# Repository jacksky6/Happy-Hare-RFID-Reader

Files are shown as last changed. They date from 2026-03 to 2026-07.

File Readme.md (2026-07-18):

# Happy Hare RFID/NFC Reader

NFC spool identification for Happy Hare. Use one NFC reader on each EMU lane, one shared reader inside the MMU body, or both. PN532 remains the default reader; PN7160, RC522, and PN5180 are available with `reader_type: pn7160`, `rc522`, and `pn5180`.

This is a system-level Klipper integration, not a plug-and-play appliance. It touches Klipper extras, Happy Hare macros, lane MCU firmware, I2C wiring, Spoolman, and optional LED effects. If you are not comfortable recovering from a Klipper config error, reflashing lane MCUs, and reading logs, expect a learning curve.

## Why This Project Is Different

Most DIY spool RFID/NFC systems put a small controller such as an ESP32 near the
reader and report tags over WiFi, MQTT, or another side channel. Others wire the
reader back to the host Raspberry Pi, which often means long SDA/SCL or USB runs
through the printer.

This project keeps the reader inside the MMU wiring domain. Each NFC reader is
connected directly to an existing Klipper MCU I2C bus, usually the MMU board or
the per-lane board inside the MMU. Klipper talks to that MCU, and the plugin
integrates the result with Happy Hare and Spoolman.

Practical hardware choices:

- **EMU / one board per lane:** per-lane readers are a natural fit. Each lane has
  its own MCU/I2C bus, so PN532 and PN7160 are both valid choices.
- **Other B-style multi-material systems with one MMU board:** PN7160 is usually
  the better choice for multiple readers on one bus because it has four
  selectable I2C addresses (`40-43` / `0x28-0x2B`). That matches many four-color
  MMU layouts.
- **Single shared reader:** PN532, PN7160, RC522, or PN5180 can be mounted
  inside the MMU body and used as a tap-before-loading reader. PN5180 is the
  SPI option when SLIX2 (ISO15693/Type-5) support is required.

For EMU installations, [`NFC Mounting Bracket/`](NFC%20Mounting%20Bracket/)
contains the printable STL and editable STEP source for the NFC-reader LED holder.

## Virtual Endstop — How Scan-Jog Finds the Tag

Per-lane installs register each lane's NFC reader as a real Klipper/Happy Hare
homing endstop (`mmu_nfc_endstop.py`, `[mmu_nfc_endstop laneN]`) — no extra
hardware or wiring, it borrows the reader the matching `[nfc_gate laneN]`
section already owns. When scan-jog searches for the tag, the forward search
is a genuine Klipper homing move (`ENDSTOP=nfc_lane<N>`) that stops the
instant the tag is detected, instead of jogging a fixed chunk and polling
afterward and hoping the tag was somewhere in that chunk. This is generated
automatically for every enabled lane by `install.sh` — there is nothing extra
to configure. See [How It Works](docs/shared/how-it-works.md) for the full
scan loop and [Configuration Reference](docs/shared/configuration.md) for the
`[mmu_nfc_endstop laneN]` keys.

The same configuration supports Happy Hare V3 and V4. The plugin registers
the software endstop on V3's shared gear rail or on the V4 drive selected by
the reader's `mmu_gate`. Lane and endstop section names are only labels; the
`nfc_gate` reference and `mmu_gate` value provide the actual binding, including
multi-unit installations.

## Operating Modes

| Mode | Hardware | Best For | Flow |
|---|---|---|---|
| Per-lane readers | One NFC reader per EMU gate/lane MCU (default PN532; PN7160, RC522, or PN5180 supported) | Automatic spool identification during lane preload | Load spool -> HH parks filament -> NFC scan-jog rotates spool -> Spoolman lookup -> HH gate map |
| Shared reader | One NFC reader mounted inside the MMU body (PN532, PN7160, RC522, or PN5180) | Fewer readers, manual tap before loading | Tap tag -> spool staged -> load any gate -> HH pregate preload -> staged spool assigned |
| Hybrid | Per-lane readers plus shared reader | Normal lanes with per-lane readers, plus shared/bypass workflows | Lane readers handle scan-jog; shared reader stages tapped spools for preload |

The shared reader can stage only a real Spoolman spool ID. UID lookup, embedded spool IDs, and auto-created Spoolman records work. Metadata-only tags without a Spoolman spool ID cannot be staged for Happy Hare preload.

## Requirements

- Voron/EMU setup running the [igiannakas IG-dev branch of Happy Hare](https://github.com/igiannakas/Happy-Hare/tree/IG-dev), which provides `variable_user_post_preload_extension`
- One Klipper MCU per filament lane for per-lane reader installs, or one MCU hosting the shared NFC reader
- Supported NFC reader hardware configured for its bus
- Hardware I2C or SPI bus on the MCU hosting the NFC reader
- Klipper version requirements:
  - Strongly recommended: use the latest Klipper on the host and every MCU
    hosting an NFC reader. The NFC drivers use Klipper's newer low-level
    `i2c_transfer` / `i2c_bus_status` path so bus errors such as `START_NACK`
    can be handled on the host side instead of turning reader faults into
    Klipper shutdowns.
  - If checking an older install, it should be newer than upstream commit
    `6bbc9069` (`bus: Note mcu code deprecation if missing i2c_transfer`,
    Feb 24, 2026 on GitHub).
  - After updating Klipper, rebuild and flash every MCU hosting an NFC reader.
- Spoolman reachable from the Pi
- NFC tags on spools: NTAG213/215/216, MIFARE Classic, or supported rich-tag formats
- Lane MCU firmware rebuilt from the same Klipper checkout as the host

## Happy Hare V4 Compatibility

Happy Hare v4 can run the post-preload hook while the MMU reports
`action=checking`. For automatic gate-status polling, NFC treats `checking` as
scan-safe only when the detected Happy Hare major version is 4 or newer. For
the post-preload hook, `_NFC_SCAN_JOG_PRELOAD` sends
`NFC GATE=<n> JOG_SCAN=1 SOURCE=AUTO`; that trusted hook path uses the same
version-aware scan-safe check: Happy Hare v4 accepts `action=idle` or
`action=checking`; Happy Hare v3/pre-v4 and unknown versions accept only
`action=idle`. Manual or console `JOG_SCAN=1` commands without `SOURCE=AUTO`
stay conservative and always require `action=idle`.

Happy Hare V4 also validates `MMU_SET_LED` effect names against its configured
operation effects. NFC therefore starts generated `[mmu_led_effect]` instances
directly on V4, while keeping the existing public `MMU_SET_LED` path on V3.
No LED configuration changes are required: define NFC effects with
`define_on: gates` (or `define_on: gates, exit`) as usual.

Supported readers:

| Reader | `reader_type` | Bus / address | Notes |
|---|---|---|---|
| PN532 | `pn532` | `36` (`0x24`) | Default reader and documented PN532 wiring path |
| PN7160 | `pn7160` | `40-43` (`0x28-0x2B`) | Supports NTAG/Type2, ISO15693/Type5, and authenticated Bambu/MIFARE reads |
| RC522 | `rc522` | SPI (`cs_pin` + `spi_bus`/software SPI pins) | UID lookup, NTAG/Type-2 rich reads, and authenticated MIFARE/Bambu reads; no ISO15693 |
| PN5180 | `pn5180` | SPI (`cs_pin`, `spi_bus`/software SPI pins, `busy_pin`, `reset_pin`) | ISO14443A/NTAG, authenticated MIFARE/Bambu, and SLIX2 (ISO15693/Type-5) reads; see the SLB nine-wire wiring guide |

Supported tag formats:

| Tag / data path | PN532 | PN7160 | RC522 | PN5180 | Notes |
|---|---:|---:|---:|---:|---|
| Spoolman UID lookup | Yes | Yes | Yes | Yes | Default path. The tag only needs a readable factory UID registered in Spoolman's extra field. |
| NTAG / NFC Type 2 rich tags | Yes | Yes | Yes | Yes | NDEF text/URI/MIME/JSON payloads, OpenSpool, OpenTag3D, TigerTag, OpenPrintTag text-compatible payloads, and several manufacturer binary tags. |
| MIFARE Classic rich tags | Yes | Yes | Yes | Yes | Bambu, QIDI Box, and Creality CFS all require `tag_parsing: True` and `bambu_reads: True`. Bambu's own keys and Creality's UID-derived Key B both additionally require `pycryptodome`; QIDI uses a factory-default-key fallback that needs no extra dependency (see [Configuration Reference](docs/shared/configuration.md#tag-data-parsing)). |
| SLIX2 / ISO15693 Type 5 rich tags | No | Yes | No | Yes | Current Type-5 rich-read path is for SLIX2 tags. Its payload enters the normal parser and is not limited to OpenPrintTag. Official OpenPrintTag antenna size is best suited to a shared reader; per-lane use needs hardware testing. |

The vendored parser currently recognizes Bambu Lab, ELEGOO, Anycubic ACE,
TigerTag, Creality CFS/K1/K2, QIDI Box, SimplyPrint/QIDI URL tags, OpenTag3D,
OpenSpool, OpenPrintTag, and generic NDEF JSON filament records. See
[Spoolman Integration](docs/shared/spoolman-integration.md) for format details
and auto-create behavior. Bambu, TigerTag/TigerTag+, and tested Creality
CFS/K1/K2 rich tags also expose parser-derived same-spool `spool_identity`
values for scan-jog left-neighbor interference handling.

## Documentation

| Guide | Purpose |
|---|---|
| [NFC Reader Wiring](docs/i2c-nfc/wiring.md) | PN532, PN7160, RC522, and PN5180 wiring; includes the PN5180 SLB nine-wire guide |
| [Install & Uninstall](docs/shared/install-uninstall.md) | Installer behavior, includes, updates, removal |
| [First-Time Setup](docs/i2c-nfc/setup.md) | Configure Spoolman, lane hardware, first verification |
| [Shared Reader](docs/shared/shared-reader.md) | Shared-reader workflow, hook wiring, commands, LED behavior |
| [Configuration Reference](docs/shared/configuration.md) | Every config key, defaults, inheritance rules |
| [Commands & Macros](docs/shared/klipper-functions.md) | User commands, shared commands, callback macros |
| [Message Definitions](docs/shared/message_definition.md) | Console output and matching `nfc_reader.log` entries |
| [Spoolman Integration](docs/shared/spoolman-integration.md) | Extra field setup, UID registration, lookup behavior |
| [Troubleshooting](docs/i2c-nfc/troubleshooting.md) | Startup errors, reader failures, tag lookup issues |
| [How It Works](docs/shared/how-it-works.md) | Boot sequence, poll flow, scan-jog, dispatch layers |
| [Expert I2C Debugging](docs/shared/expert-low-level-i2c-debugging.md) | Low-level PN532 probe commands |

## Quick Install

Before installing, rebuild and flash Klipper firmware on every MCU that will host an NFC reader. Host and MCU firmware version mismatches produce I2C failures that look like wiring or reader problems.

```bash
cd ~
git clone https://github.com/cwiegert/Happy-Hare-RFID-Reader.git rfid-reader
cd ~/rfid-reader
bash install.sh
```

Beta cutover note: if an old `~/emu-nfc-reader` install exists, the installer prompts before backing it up/removing it and continuing with a fresh `~/rfid-reader` install.

Add the includes to `printer.cfg` in this order.

Per-lane readers:

```ini
[include nfc/nfc_reader.cfg]
[include nfc/nfc_macros.cfg]
[include nfc/nfc_reader_hw.cfg]
```

Shared-reader-only:

```ini
[include nfc/nfc_reader.cfg]
[include nfc/nfc_macros.cfg]
[include nfc/nfc_reader_shared.cfg]
```

Hybrid:

```ini
[include nfc/nfc_reader.cfg]
[include nfc/nfc_macros.cfg]
[include nfc/nfc_reader_hw.cfg]
[include nfc/nfc_reader_shared.cfg]
```

Set Spoolman in `~/printer_data/config/nfc/nfc_reader.cfg`:

```ini
[nfc_gate]
spoolman_url:      auto
spoolman_rfid_key: rfid_tag
```

For shared-reader installs, wire Happy Hare's post-preload hook:

```ini
[gcode_macro _MMU_SEQUENCE_VARS]
variable_user_post_preload_extension: '_NFC_SHARED_PRELOAD'
```

Restart Klipper and run the doctor:

```bash
sudo systemctl restart klipper
```

```gcode
NFC_DOCTOR
NFC_STATUS
```

## Common Commands

```gcode
NFC_HELP                                      ; show normal command help
NFC_HELP ADVANCED=1 CALLBACKS=1 LOW_LEVEL=1  ; show the full command set
NFC_DOCTOR                                   ; check common config/setup problems
NFC_STATUS                                   ; show every configured lane/shared reader
NFC_REGISTER UID=04A1B2C3D4 SPOOL_ID=123     ; link a known UID to an existing Spoolman spool
NFC_LED_TEST ALL=1 CYCLES=2                  ; chase-test lane tag-read LEDs on all enabled lanes
NFC GATE=0 INIT=1                            ; re-run reader init on one lane reader
NFC GATE=0 SCAN=1                            ; raw UID scan, no Spoolman/HH dispatch
NFC GATE=0 LED_TEST=1 CYCLES=2               ; test lane tag-read LED on one gate
NFC GATE=0 POLL=1                            ; read, resolve, and dispatch once
NFC GATE=0 JOG_SCAN=1                        ; run scan-jog manually; blocked if HH gate is empty
NFC GATE=0 READ=1                            ; start lane background polling
NFC GATE=0 READ=0                            ; stop lane background polling
NFC_SHARED STATUS=1                          ; show shared-reader state
NFC_SHARED READ=1                            ; start shared-reader polling
NFC_SHARED REPLACE=1                         ; discard staged shared spool and scan another
NFC_SHARED CANCEL=1                          ; cancel staged shared spool
```

## Key Defaults

These are the defaults shipped in `config/nfc_reader.cfg`:

| Setting | Default | Notes |
|---|---:|---|
| `startup_polling` | `1` | Start polling after reader init succeeds |
| `poll_interval` | `10` | Per-lane background poll interval in seconds |
| `absent_threshold` | `3` | Missed polls before a removal event |
| `scan_enabled` | `False` | Disables automatic gate-status scan-jog trigger; manual/hook `JOG_SCAN` still works |
| `scan_jog_mm` | `150.0` | Logical scan chunk divided into three stopped-position substeps |
| `scan_jog_max` | unset | Optional fixed scan-jog travel limit; leave unset to use the lane Bowden length |
| `scan_reads_per_position` | `1` | Reads per stopped scan position |
| `scan_poll_interval` | `0.25` | Read spacing during scan-jog and shared-reader polling cadence |
| `scan_motion_mode` | `continuous` | `continuous` homes the forward search against the lane's virtual NFC endstop, stopping the instant the tag is detected; `stopped` keeps blocking substep reads |
| `scan_continuous_step_mm` | `150.0` | Continuous-mode forward chunk size. Rich reads use the observed UID hit-window center, so this no longer needs to be kept small for rich-tag positioning |
| `scan_continuous_speed` | `200.0` | Continuous-mode gear move speed |
| `scan_continuous_accel` | `2000.0` | Continuous-mode gear move acceleration |
| `scan_continuous_poll_interval` | `0.05` | In-flight NFC read cadence while a continuous chunk is estimated to be moving |
| `debug` | `2` | Warnings and errors in `nfc_reader.log` |
| `console_output` | `False` | Keep routine NFC logs out of the console |

To try continuous scan-jog:

```ini
[nfc_gate]
scan_motion_mode: continuous
scan_continuous_step_mm: 150.0
scan_continuous_speed: 200.0
scan_continuous_accel: 2000.0
scan_continuous_poll_interval: 0.05
```

Continuous mode preserves the existing tag-found flow: the read-light effect
plays for about 0.1 second, then NFC rewinds and dispatches the cached tag/spool
action just like stopped mode.
If a UID is found during motion, continuous mode waits for the current chunk to
finish and checks Spoolman first. If rich tag parsing is still needed, NFC
recenters to the observed UID hit-window center before running rich parsing and
the normal rich-read retry sweep.

Set `enabled: False` on a `[nfc_gate laneN]` or `[nfc_gate shared]` section to keep the config block in place without initializing hardware or registering commands for that reader.

## MCU Firmware Warning

The NFC reader driver talks to firmware running on the MCU, not only to Klipper on the Pi. After updating Klipper, rebuild and flash every lane/shared MCU that hosts an NFC reader before debugging NFC.

Recommended update order:

```text
1. Update the Klipper host checkout.
2. Build MCU firmware from that same checkout.
3. Flash every MCU that hosts an NFC reader.
4. Restart Klipper.
5. Confirm all MCUs reconnect before testing NFC.
```

When host and MCU firmware are out of sync, common symptoms include reader init failures, `i2c_read_response` timeouts, and other devices on the same I2C bus failing unexpectedly.

## License

Copyright (C) 2026 WoodWorker.
Licensed under [GNU General Public License v3.0 or later](https://www.gnu.org/licenses/gpl-3.0.html).
See [LICENSE](LICENSE) for the full terms.

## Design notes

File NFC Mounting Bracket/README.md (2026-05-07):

# NFC Mounting Bracket Files

These files are PN532 reader mounts for the EMU lane LED holder area.

## Standard Height

Use the standard NFC bracket files when your tag placement is not tied to the
factory Bambu spool tag height, or when you are tuning the reader position for
your own spool/tag layout.

- `LED_holder_No_cover_with_NFC.stl`
- `LED_holder_No_cover_with_NFC.step`
- `LED_holder_NFC_Guard.stl`
- `LED_holder_NFC_Guard.step`

## Bambu Height

The `Bambu_height` variants place the PN532 reader center at the same height as
the RFID/NFC tags on standard Bambu spools. Use these when you want the reader
antenna aligned to Bambu spool tags without modifying tag placement.

- `LED_holder_with_NFC_Bambu_height.stl`
- `LED_holder_NFC_Guard_Bambu_height.stl`

## Guard vs No Cover

The guard version protects the PN532 reader DIP switches. This is especially
useful with open-sided spools, where the spool edge can otherwise catch on the
reader's switches as the spool turns and stall the lane's stepper. The no-cover
version keeps the reader more exposed and may be useful for fit checks, tuning,
or tight clearance builds.

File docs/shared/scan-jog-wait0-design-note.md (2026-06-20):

# Scan-Jog WAIT=0 Motion Mode Design Note

This is a memory/design note for a future scan-jog mode that experiments with
Happy Hare `MMU_TEST_MOVE WAIT=0`. It is not implemented in current `main`.

## Goal

Current scan-jog uses stopped-position reads:

1. Queue `MMU_TEST_MOVE` with default `WAIT=1`.
2. Happy Hare blocks until the move completes.
3. NFC reads at the stopped spool position.
4. Repeat until tag found or max scan distance reached.

The proposed mode keeps the Klipper/Happy Hare integration inside Klipper, but
uses small non-blocking moves so NFC can poll between queued motion chunks:

1. Queue a small `MMU_TEST_MOVE ... WAIT=0`.
2. Poll the reader while that short move is completing or just after it.
3. If a tag is found, stop queuing more moves.
4. Let the current small move finish, then rewind/park through the existing
   scan-jog finish path.

This avoids a full external NFC daemon and keeps the blast radius small.

## Proposed Config

```ini
# Existing/default behavior.
scan_motion_mode: stopped

# Experimental behavior.
# scan_motion_mode: continuous

# Small non-blocking chunks used only in continuous mode.
scan_continuous_step_mm: 50.0

# Delay between one estimated move completion and queueing the next move.
# During this gap, poll the reader once for a tag.
scan_continuous_poll_interval: 0.05

# Explicit continuous scan move settings.
scan_continuous_speed: 150.0
scan_continuous_accel: 2000.0
```

Keep `stopped` as the default until the continuous model is proven reliable.

`MMU_TEST_MOVE` defaults to the `gear` motor in Happy Hare, so continuous mode
does not need to pass `MOTOR=gear` unless we want the generated command to be
extra explicit. The important behavior change is `WAIT=0`.

## Motion Model

Initial continuous values:

- Move length: `50.0` mm
- Move speed: `150.0` mm/s
- Move accel: `2000.0` mm/s^2
- Inter-move delay / tag-check window: `0.05` s

For a 50 mm move at 150 mm/s with 2000 mm/s^2 acceleration:

- Accel time to 150 mm/s: `150 / 2000 = 0.075` s
- Accel distance: `150^2 / (2 * 2000) = 5.625` mm
- Decel distance: `5.625` mm
- Cruise distance: `50 - 5.625 - 5.625 = 38.75` mm
- Cruise time: `38.75 / 150 = 0.258` s
- Total motion time per 50 mm chunk: about `0.408` s
- Average speed during the moving part: about `122` mm/s
- Average scan advance including the 0.05 s gap: about `109` mm/s

So the spool advances in 50 mm non-blocking chunks, with a short stationary-ish
gap between chunks. The first implementation should check for a tag during that
0.05 s gap after each chunk completes, then either queue the next chunk or stop
the jog flow and let the existing tag handling finish the scan.

The existing `finish()` path intentionally pauses for about 0.1 second after a
tag is found so the `scan_tag_read_effect` / read-light effect is visible before
the rewind effect starts. Continuous mode should keep that behavior. The motion
change is only the forward jog pacing.

## State Additions

Add these fields to `NFCGate` / scan-jog state:

```python
gate._scan_motion_mode = 'stopped'
gate._scan_continuous_step_mm = 50.0
gate._scan_continuous_poll_interval = 0.05
gate._scan_continuous_speed = 150.0
gate._scan_continuous_accel = 2000.0

gate._scan_continuous_move_inflight = False
gate._scan_continuous_move_complete_time = 0.0
gate._scan_continuous_last_move_mm = 0.0
```

`_scan_mm_total` remains the authoritative planned scan distance for rewind.

## Existing Stopped Mode

Leave the current `scan_jog.step_event()` path intact:

```python
if gate._scan_motion_mode == 'stopped':
    return stopped_step_event(gate, eventtime)
```

This preserves current behavior and makes continuous mode opt-in.

## Continuous Mode Pseudocode

```python
def step_event(gate, eventtime):
    if gate._scan_motion_mode != 'continuous':
        return stopped_step_event(gate, eventtime)
    return continuous_step_event(gate, eventtime)
```

```python
def continuous_step_event(gate, eventtime):
    if not gate._scan_mode:
        return gate.reactor.NEVER

    if is_printing(gate):
        gate._rewind_and_exit_scan()
        return gate.reactor.NEVER

    run_pending_hh_prep(gate)

    now = gate.reactor.monotonic()

    # First, poll NFC. This happens after the previous small move has completed
    # or before the first move is queued. A tag hit stops future queued motion.
    try:
        tag_found = gate._poll()
    except Exception:
        logger.exception("[%s]: continuous scan poll error", gate._name)
        gate._console("[ERROR] NFC[%s]: scan poll failed" % gate._name)
        tag_found = False

    if tag_found:
        if handle_left_neighbor_interference(gate):
            if not gate._scan_mode:
                return gate.reactor.NEVER
            return now + gate._scan_continuous_poll_interval

        if current_tag_decode_incomplete(gate):
            # Prefer the existing decode retry machinery. The simplest first
            # implementation can temporarily fall back to stopped retry moves.
            if retry_incomplete_decode(gate, now):
                return now + gate._scan_continuous_poll_interval

        # Do not queue more motion. Let the current small move complete if the
        # estimate says it is still active, then use the existing finish path.
        if gate._scan_continuous_move_inflight and now < gate._scan_continuous_move_complete_time:
            return gate._scan_continuous_move_complete_time

        # Use the same tag read actions, read-light hold, rewind, and scan
        # completion logic as stopped mode. The only behavior being changed is
        # how the forward jog motion is paced.
        gate._finish_scan()
        return gate.reactor.NEVER

    if gate._scan_mm_total >= gate._scan_max_mm:
        gate._rewind_and_exit_scan()
        return gate.reactor.NEVER

    # If a previous non-blocking move is still expected to be in progress,
    # poll again soon instead of stacking another move.
    if gate._scan_continuous_move_inflight:
        if now < gate._scan_continuous_move_complete_time:
            return gate._scan_continuous_move_complete_time
        gate._scan_continuous_move_inflight = False

        # After each completed chunk, wait 0.05 s, poll once, and only then
        # queue the next chunk if no tag was found.
        return now + gate._scan_continuous_poll_interval

    # Queue one small non-blocking movement chunk.
    remaining = gate._scan_max_mm - gate._scan_mm_total
    move = min(gate._scan_continuous_step_mm, remaining)
    if move <= 0.0:
        gate._rewind_and_exit_scan()
        return gate.reactor.NEVER

    queue_continuous_jog(gate, move)
    gate._scan_mm_total += move
    gate._scan_continuous_last_move_mm = move
    gate._scan_continuous_move_inflight = True
    gate._scan_continuous_move_complete_time = (
        now + chunk_interval(gate, move))

    return now + gate._scan_continuous_poll_interval
```

## Jog Command Pseudocode

```python
def queue_continuous_jog(gate, move):
    speed = getattr(gate, '_scan_continuous_speed', 150.0)
    accel = getattr(gate, '_scan_continuous_accel', 2000.0)
    cmd = (
        "MMU_TEST_MOVE MOVE=%.2f SPEED=%.1f ACCEL=%.1f WAIT=0 QUIET=1"
        % (move, speed, accel)
    )
    gate.printer.lookup_object('gcode').run_script(cmd)
```

If Happy Hare ignores `QUIET=1` on `MMU_TEST_MOVE`, omit it.

## Safety Notes

- Do not queue another `WAIT=0` move until the estimated completion time for
  the prior small move has passed.
- Use the existing tag read actions and existing scan completion logic after a
  tag is found. Continuous mode only changes how jog moves are queued.
- Preserve the existing 0.1 s read-light hold before rewind.
- With 50 mm chunks, worst-case tag overshoot is roughly one chunk plus the
  0.05 s check gap and scheduler latency.
- Do not attempt true emergency mid-move stop in the first implementation.
- Let the current small move finish before `_finish_scan()` or rewind.
- Preserve the existing stopped-position decode retry path initially.
- Keep `scan_motion_mode: stopped` as the default.

## Initial Test Values

```ini
scan_motion_mode: continuous
scan_continuous_step_mm: 50.0
scan_continuous_poll_interval: 0.05
scan_continuous_speed: 150.0
scan_continuous_accel: 2000.0
```

Expected behavior:

- Scan should move in 50 mm non-blocking gear chunks.
- Each chunk should take about 0.408 s, then pause/check for about 0.05 s before
  the next chunk is queued.
- Effective scan advance should be roughly 109 mm/s with these defaults.
- If a tag is read during the check window, no more motion is queued and the
  existing tag read actions, 0.1 s read-light hold, rewind, and completion logic
  run.
- Rewind distance should still be based on `_scan_mm_total`, so the existing
  parking handoff remains usable.

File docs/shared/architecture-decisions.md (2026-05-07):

# Architecture Decisions

[← Back to README](../../Readme.md)

---

This document captures the design decisions made while building the PN532 I2C path, including the reasoning and trade-offs behind each choice. It is meant to explain *why* the system is structured the way it is — so that future changes can be made with the context that drove the original decisions.

---

## Decision: Strict Layer Ownership

**What we decided:** Each layer owns exactly one responsibility and may not reach across its boundary into another layer's domain.

| Layer | Owns | Explicitly does not own |
|---|---|---|
| `PN532Driver` | PN532 wire protocol, I2C frames, UID extraction | Spoolman, gate policy, Happy Hare commands |
| `SpoolmanClient` | UID → spool record lookup and cache | Gate state, lane assignment, MMU commands |
| `NFC_Manager` | Gate state machine, changed/removed decisions, macro dispatch | PN532 protocol details |
| `nfc_macros.cfg` | Happy Hare-facing GCode calls | NFC bus reads, Spoolman HTTP requests |

**Why:** The alternative was a flat design where one module reads the tag, queries Spoolman, and calls `MMU_GATE_MAP`. We rejected this because it creates a single module that breaks for three independent reasons: hardware issues, Spoolman API changes, and Happy Hare version differences. Each layer now has a single reason to change.

**The boundary that matters most:** `SpoolmanClient` never calls Happy Hare. `PN532Driver` never calls Spoolman. NFC_Manager is the only module that sees both a UID and a gate assignment, and it dispatches a macro rather than calling Happy Hare directly.

---

## Decision: Tags Are Read-Only — UID Lookup Only

**What we decided:** The system reads the factory UID only. Tags are never written to. The UID is stored as a Spoolman extra field on the spool record.

**Why we rejected writing tags:** Writing tag payload data would require:
- A tag format standard (which format? which pages? how versioned?)
- A tag programming workflow for users
- Handling format mismatches on old tags after upgrades
- Dealing with write failures and partially-written tags

The UID approach requires none of this. Any blank NFC sticker from any supplier works. The spool association is managed entirely in Spoolman. If you need to associate a different spool with a tag, you update one extra field in Spoolman — the tag is unchanged.

**Trade-off accepted:** The tag must be registered in Spoolman before it can resolve to a spool. An unregistered tag produces `_NFC_TAG_NO_SPOOL` instead of silently failing.

---

## Decision: SpoolmanClient Is a Pure Lookup Client

**What we decided:** SpoolmanClient resolves UID → spool record and caches results. It does not PATCH Spoolman location, and it does not call `MMU_GATE_MAP`, `MMU_SPOOLMAN`, or any Happy Hare command.

**Why:** The gate a spool belongs to is a *physical fact*, not a Spoolman record fact. Spoolman knows spool IDs and filament metadata. It does not know the MMU gate layout. The thing that knows both a spool ID and a gate number is NFC_Manager — and that is exactly where the gate assignment decision lives.

Keeping Happy Hare commands and gate-aware Spoolman writes out of SpoolmanClient means it can still be used from any context where you have a UID and need a spool ID. Happy Hare owns gate map state and synchronizes that state to Spoolman via `MMU_SPOOLMAN SYNC=1 QUIET=1` in `nfc_macros.cfg`.

---

## Decision: Happy Hare Calls Are Behind `_NFC_*` Macros

**What we decided:** NFC_Manager dispatches three GCode macros. Those macros call `MMU_GATE_MAP` for Happy Hare runtime state and pass `SYNC=1` when we want Happy Hare to synchronize the gate map to Spoolman. NFC_Manager does not call Happy Hare commands directly.

```
NFC_Manager → _NFC_SPOOL_CHANGED GATE=n SPOOL_ID=id UID=uid
           → _NFC_SPOOL_REMOVED  GATE=n
           → _NFC_TAG_NO_SPOOL   GATE=n UID=uid

nfc_macros.cfg → MMU_GATE_MAP GATE={gate} SPOOLID={spool_id} AVAILABLE=1 SYNC=1 QUIET=1
```

**Why:** Happy Hare's GCode API evolves between versions. The exact command for "tell Happy Hare about this spool" belongs in editable GCode config, not Python. The default macro is designed for Happy Hare `spoolman_support: push`: `MMU_GATE_MAP` sets the local runtime gate map and `SYNC=1` lets Happy Hare synchronize that local map to Spoolman. NFC_Manager already knows the physical gate that produced the read, so it passes both `GATE` and `SPOOL_ID` into the macro boundary.

This also makes the integration boundary visible. Anyone debugging a Happy Hare integration problem knows to look in `nfc_macros.cfg` — not in `pn532_driver.py`.

**Corollary:** If a Happy Hare version requires a different synchronization command, adjust `nfc_macros.cfg`. Do not add it to `PN532Driver` or `SpoolmanClient`.

---

## Decision: Removal Is Debounced

**What we decided:** A single missed read does not declare a spool removed. The gate must be absent for `poll_interval × absent_threshold` seconds before `_NFC_SPOOL_REMOVED` fires.

Default:
```ini
poll_interval:    30   # seconds
absent_threshold: 3    # consecutive missed reads
# ≈ 90 seconds before removal fires
```

**Why:** NFC reads can miss for reasons that have nothing to do with spool removal: tag angle, distance, vibration, RF interference from steppers, or a single delayed I2C transaction. If removal fired on every miss, a spool sitting in a gate would trigger constant remove/detect cycles during a print.

90 seconds of absence is unambiguous. If a spool is physically gone, 90 seconds is fast enough to be useful. If it was a transient read miss, it recovers on the next successful poll.

---

## Decision: Per-Lane I2C Bus (One PN532 Per EBB42)

**What we decided:** Each gate has one PN532, wired to the I2C bus on that lane's EBB42. There is no shared I2C bus across lanes.

**Why we chose this over a shared bus / multiplexer:**
- No I2C address management. Every PN532 can stay at `0x24` because they are on separate buses.
- No multiplexer hardware (`TCA9548A` or similar) to buy, wire, or configure.
- Failures are isolated. A PN532 that holds SDA low only affects one lane.
- The lane MCU already exists as part of the Happy Hare hardware setup. Its I2C bus is available with no extra wiring effort.

**Trade-off accepted:** This design only works when each lane has its own MCU. A printer with a single MCU for all lanes would need a different approach (multiplexer or shared bus with unique addresses).

---

## Decision: NFC_Manager Owns the Baseline Startup Policy

**What we decided:** On startup, NFC does not blindly overwrite Happy Hare's gate map with whatever the readers see at boot time.

**Why:** Happy Hare already starts with a known gate/filament map from its own config and persisted state. Tags may not be physically near readers at startup. A spool may be in a gate but temporarily unreadable. If NFC declared every gate empty on boot and then started filling them in as reads succeed, it would create a noisy burst of `MMU_GATE_MAP ... SYNC=1` updates during Klipper startup.

**Current implication:** NFC_Manager treats reads as events (state changes), not as complete authority over the gate map. It updates Happy Hare when something changes, not when it confirms that the gate is in the state it was already in.

**Future work:** A proper baseline sync — querying Happy Hare state at startup and comparing it with what the readers see — is the right long-term approach. This would let NFC detect discrepancies between persisted state and physical reality after a power cycle.

---

## Decision: Expert I2C Debug Commands Are Hidden by Default

**What we decided:** The low-level PN532 bus commands (`STEP=`, `RAW_READ`, `RAW_WRITE`, etc.) are not available unless `low_level_debug: True` is set explicitly.

**Why:** Raw bus commands can disturb the PN532 state machine. Sending `PASSIVE_WRITE` without following up with `PASSIVE_ACK` and `PASSIVE_RESPONSE` leaves the PN532 waiting for a read that never comes, which can cause subsequent normal polls to fail until the reader is reinitialized. These commands are useful for bring-up diagnostics but would be confusing and dangerous in normal operation.

Gating them behind a config flag means they are discoverable for bring-up but cannot be called accidentally.

---

## Decision: Python Extras Are Symlinked, Not Copied

**What we decided:** `install.sh` creates symlinks from Klipper's extras directory into the repo clone. It does not copy files.

**Why:** If files were copied, every update would require running `install.sh` to copy the new versions. With symlinks, `git pull` in the repo directory is sufficient — Klipper reads the updated Python files directly from the repo at next restart. The Moonraker update manager calls `install.sh` after a `git pull`, which updates the symlinks if they ever change targets. But for normal code-only updates, the symlinks just keep working.

**Implication:** The repo clone must remain present on the Pi. If the repo is deleted, the symlinks break and Klipper will fail to start.

---

## Decision: Config Files Are User-Owned (Non-Destructive Merge)

**What we decided:** `install.sh` never overwrites a config file section the user has already configured. On subsequent runs, it only appends sections that are missing.

**Why:** Config files in `~/printer_data/config/nfc/` are part of the user's printer configuration. Overwriting them on update would destroy local customizations — particularly in `nfc_macros.cfg` where users may have adapted the Happy Hare calls for their version, and in `nfc_reader_hw.cfg` where the exact lane names and MCU names are specific to each user's hardware.

The merge strategy (copy-if-absent, append-missing-sections) means that new features that add new config sections are picked up on the next `install.sh` run, while existing customizations survive.

---

## Boundary Summary

```
┌─────────────┐    UID only    ┌──────────────────┐   spool_id    ┌────────────────┐
│ PN532Driver │ ─────────────► │   NFC_Manager    │ ────────────► │ SpoolmanClient │
│             │                │                  │               │                │
│ I2C frames  │                │ gate state       │               │ UID lookup     │
│ UID extract │                │ changed/removed  │               │ cache          │
└─────────────┘                │ macro dispatch   │               └────────────────┘
                               └────────┬─────────┘
                                        │ _NFC_SPOOL_CHANGED
                                        │ _NFC_SPOOL_REMOVED
                                        │ _NFC_TAG_NO_SPOOL
                                        ▼
                               ┌─────────────────┐
                               │  nfc_macros.cfg  │
                               │                  │
                               │  MMU_GATE_MAP    │
                               │  MMU_SPOOLMAN    │
                               │  (Happy Hare)    │
                               └─────────────────┘
```

No layer reaches back up the stack. No layer reaches sideways. The only direction is down and out through the macro boundary.

---

*Copyright (C) 2026 WoodWorker. Licensed under [GPL-3.0-or-later](https://www.gnu.org/licenses/gpl-3.0.html) — see [LICENSE](../../LICENSE).*

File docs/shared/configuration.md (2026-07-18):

# Configuration Reference

[← README](../../Readme.md) | [Commands & Macros →](klipper-functions.md)

---

## Config File Overview

Three files, included in this order from `printer.cfg`:

```ini
[include nfc/nfc_reader.cfg]    ; base settings — edit this
[include nfc/nfc_macros.cfg]    ; Happy Hare event macros — edit only if needed
[include nfc/nfc_reader_hw.cfg] ; one section per physical gate — edit this
```

For a shared-reader-only install, include `nfc_reader_shared.cfg` instead of
`nfc_reader_hw.cfg`. For a hybrid install, include both hardware files after
`nfc_macros.cfg`.

**How inheritance works:** `nfc_reader.cfg` defines the base `[nfc_gate]` section with all defaults. Each `[nfc_gate laneN]` in `nfc_reader_hw.cfg` inherits every key automatically. Override a key in a lane section only when that lane needs a different value.

This includes hardware keys. `i2c_address` and `i2c_bus` set in the base `[nfc_gate]` section are inherited by all lanes — you only need to specify them per lane if a particular reader uses different hardware.

`reader_type` is inherited the same way as other hardware keys. The shipped
default is `pn532`; set `reader_type` to `pn7160`, `rc522`, or `pn5180` when
that physical reader is installed. RC522 and PN5180 use SPI rather than I2C.

Example:

```ini
[nfc_gate]
reader_type:      pn532
i2c_address:      36
i2c_bus:          i2c3_PB3_PB4
scan_enabled:     False

[nfc_gate lane0]
enabled:          True
mmu_gate:         0
i2c_mcu:          lane0
# inherits i2c_address, i2c_bus, scan_enabled=False

[nfc_gate lane1]
mmu_gate:         1
i2c_mcu:          lane1
scan_enabled:     True
# overrides only scan_enabled for lane1
```

---

## `nfc_reader.cfg` — Base Settings

### Reader Hardware

```ini
[nfc_gate]
reader_type: pn532
i2c_address: 36
i2c_bus:     i2c3_PB3_PB4
i2c_speed:   100000
```

| Setting | Default | Description |
|---|---|---|
| `reader_type` | `pn532` | Reader driver to use. Supported values are `pn532`, `pn7160`, `rc522`, and `pn5180`. |
| `i2c_address` | `36` for PN532 | I2C address. PN532 uses fixed decimal `36` (`0x24`). PN7160 must use decimal `40-43` (`0x28-0x2B`). Not used by RC522 or PN5180. |
| `i2c_bus` | board-specific | I2C bus name on the selected MCU. PN532 should use hardware I2C. PN7160 supports software I2C, but hardware I2C is recommended because software I2C increases MCU load. Not used by RC522 or PN5180. |
| `i2c_speed` | `100000` | I2C speed in Hz. Keep `100000` for PN7160 and for conservative PN532 bring-up. |
| `i2c_mcu` | per section | Klipper MCU name that hosts the reader. Required in `[nfc_gate laneN]` and `[nfc_gate shared]`. |
| `cs_pin` | unset | Required for RC522 and PN5180 SPI readers. Use the Klipper pin connected to RC522 SDA/SS/CS or PN5180 NSS/CS. |
| `spi_bus` / software SPI pins | unset | Required for RC522 and PN5180. Use Klipper's normal SPI config keys for the selected MCU. |
| `spi_speed` | `500000` | Optional SPI clock in Hz for RC522 and PN5180. Use `500000` with hardware SPI; set `100000` for software SPI. |
| `rc522_transceive_delay` | `0.035` | Optional RC522 UID-read response wait in seconds. Leave at the default unless hardware testing shows the reader needs more time. |
| `reset_pin` | unset | Required for PN5180. Connect PN5180 RST to an MCU output so the driver can recover a communication lockup. |
| `busy_pin` | `mmu:PB0` | Required PN5180 active-high BUSY signal. The configuration key has this default, but the BUSY wire must be connected. |

Reader settings inherit from the base `[nfc_gate]` section. A lane with no
`reader_type` uses the base reader type. A lane with no `i2c_address` uses the
base address when its reader type matches the base reader type; otherwise it
uses that reader's default address.

PN7160 lane example:

```ini
[nfc_gate lane1]
enabled:     True
reader_type: pn7160
i2c_address: 40
mmu_gate:    1
i2c_mcu:     mmu1
```

PN7160 address rule: if multiple PN7160 readers share the same MCU/I2C bus,
give each reader a unique `i2c_address`. If each lane has its own MCU or its
own I2C bus, the same PN7160 address can be reused.

PN7160 optional hardware pins:

```ini
# ven_pin: PA8
# irq_pin: ^PC6
```

`ven_pin` allows a hardware reset / hard power-down. It is optional, but strongly
recommended for PN7160. Without VEN, abnormal Klipper termination can leave the
chip in a state that software cannot fully reset. `irq_pin` is also optional;
when omitted, the PN7160 driver uses timing-based polling.

RC522 lane example:

```ini
[nfc_gate lane1]
enabled:     True
reader_type: rc522
mmu_gate:    1
i2c_mcu:     mmu1
cs_pin:      mmu1:PA4
spi_bus:     spi1
# spi_speed: 500000  # Hardware SPI default; use 100000 for software SPI
# rc522_transceive_delay: 0.035
```

RC522 can resolve tags registered in Spoolman's RFID extra field and can read
NTAG/Type-2 rich metadata through the normal NFC Reader pipeline. It also
supports authenticated MIFARE Classic reads (Bambu, QIDI Box, Creality CFS)
when `tag_parsing: True` and `bambu_reads: True` are set; Bambu's own reads
and Creality's UID-derived Key B both require `pycryptodome`, QIDI's
default-key fallback does not (see [Tag Data Parsing](#tag-data-parsing)).
It does not support ISO15693 rich tag metadata.

PN5180 lane example (SLB wiring):

```ini
[nfc_gate lane0]
enabled:     True
reader_type: pn5180
mmu_gate:    0
i2c_mcu:     mmu
spi_bus:     spi2_PB14_PB15_PB13
cs_pin:      mmu:PA8
reset_pin:   mmu:PC6
busy_pin:    mmu:PB0
spi_speed:   500000
```

PN5180 supports ISO14443A/NTAG, authenticated MIFARE/Bambu, and SLIX2
(ISO15693/Type-5) reads. It requires nine physical connections on the documented
SLB setup, including both 5V and PSF 3.3V power rails, BUSY, and RST. See
[PN5180 wiring](../i2c-nfc/pn5180-wiring.md) before wiring or configuring it.

---

### Spoolman

```ini
[nfc_gate]
spoolman_url:       auto
spoolman_rfid_key:  rfid_tag
spoolman_timeout:   5.0
spoolman_cache_ttl: 300
```

| Setting | Default | Description |
|---|---|---|
| `spoolman_url` | `auto` | `auto` reads the URL from Moonraker's `[spoolman]` config. Set to `http://host:port` to use a direct URL. Set to `disabled` or leave empty to skip Spoolman lookup. |
| `spoolman_rfid_key` | `rfid_tag` | Name of the extra field on Spoolman spool records that holds the tag UID. Must match exactly — case-sensitive. |
| `spoolman_timeout` | `5.0` | HTTP request timeout in seconds. Increase if you see timeouts on a slow network. |
| `spoolman_cache_ttl` | `300` | How long (seconds) a UID→spool lookup is cached. `0` disables caching. |

---

### Tag Data Parsing

```ini
[nfc_gate]
tag_parsing:          False
bambu_reads:          False
spoolman_auto_create: False
#tag_max_pages:       16
```

| Setting | Default | Description |
|---|---|---|
| `tag_parsing` | `False` | `False` = UID-only (default — no tag content reads). `True` = read NTAG user pages or MIFARE authenticated blocks and parse filament metadata from the tag payload. |
| `bambu_reads` | `False` | Allow authenticated MIFARE Classic reads when `tag_parsing: True`. Gates three attempts, tried in order, each only firing when the previous one didn't authenticate any sector: Bambu's own per-tag HKDF-derived Key A (sectors 0-4, requires `pycryptodome`), the plain MIFARE Classic factory default Key A (sectors 0-4, QIDI Box), then Creality's UID-derived Key B (sector 1 only, requires `pycryptodome`). Despite the name, this flag also covers the QIDI/Creality fallbacks. |
| `spoolman_auto_create` | `False` | When `tag_parsing: True` and no existing Spoolman spool matches the tag, automatically create a new vendor/filament/spool record from tag metadata. Only activates when the tag carries at least a material type. |
| `tag_max_pages` | `16` | Fallback NTAG user-page window for non-NDEF/binary tags. NDEF text/JSON tags read the NDEF TLV length dynamically, so large OpenSpool/OpenPrintTag payloads do not need this increased. |

> [!NOTE]
> `bambu_reads: True` with `tag_parsing: False`, or `spoolman_auto_create: True` without tag parsing and a usable Spoolman URL, logs a startup warning and has no effect. Run `NFC_DOCTOR` after restart to see these warnings again.

> [!NOTE]
> The default-key fallback authenticates with the plain MIFARE Classic
> factory default Key A, `FF FF FF FF FF FF` — not a secret, not derived,
> the same key every unprotected MIFARE Classic card ships with. It is
> **confirmed** correct for QIDI Box tags (sourced from the community
> `BoxRFID-Touch` project, which authenticates block 4 with this exact key
> before reading/writing material/color/manufacturer codes).
> If QIDI tags fail to rich-read, see the
> [QIDI Box RFID reference](qidi-rfid-reference.md): QIDI's own tag guide
> places the payload in sector 1/block 0 (absolute block 4) and notes a
> QIDI-specific sector 1 Key A in addition to the factory fallback key.
>
> Creality CFS/K1/K2 does not use the default key at all: its sector 1 is
> protected by a Key B derived per-tag from the UID
> (`AES-128-ECB(AES_KEY_GEN, uid×4)[:6]`), and the stored payload is itself
> AES-128-ECB-encrypted with a second static key. Both keys' hex/ASCII
> values are published in the [Creality key material
> table](spoolman-integration.md#supported-rich-manufacturer-tags);
> community-sourced from a Creality RFID encryption helper script mirroring
> the JavaScript implementation used by Creality's own tag-writer tooling.
> When the default-key attempt authenticates nothing, `bambu_reads: True`
> also tries this Creality Key B against sector 1 only — if that also fails
> (or `pycryptodome` isn't installed), the read falls through to UID-only.
> Creality rich reads have been tested against real Creality spool tags. The
> parser builds a same-spool `spool_identity` from the decoded payload fields,
> not from the hardware UID, so two tags on the same spool resolve to the same
> identity for left-neighbor interference handling.

---

### Polling

```ini
[nfc_gate]
startup_polling:    1
startup_poll_delay: 0.0
poll_interval:      10
absent_threshold:   3
```

| Setting | Default | Description |
|---|---|---|
| `startup_polling` | `1` | `-1` = manual start only. `1` = start polling automatically after reader init. `0` = explicitly disabled (useful as a lane override). |
| `startup_poll_delay` | `0.0` | Seconds to wait before the first automatic poll. The shipped hardware config staggers this by 0.5 seconds per lane. |
| `poll_interval` | `10` | Seconds between polls while background polling is active. |
| `absent_threshold` | `3` | Consecutive missed reads before `_NFC_SPOOL_REMOVED` fires. At 10s interval, default = ~30s before removal. |

> [!TIP]
> For bench testing, use `poll_interval: 5` and `absent_threshold: 1` so state changes fire quickly. Restore production values before a real print run.

**Effective removal time:**
```
poll_interval × absent_threshold = seconds before removal fires
10 × 3 = 30 seconds  (default)
```

---

### Scan-and-Jog

```ini
[nfc_gate]
scan_enabled:          False
scan_jog_mm:           150.0
#scan_jog_max:         480.0
scan_reads_per_position: 1
scan_rewind_buffer_mm: 30.0
scan_decode_retry_mm:     5.0
scan_decode_retry_rounds: 5
scan_poll_interval:    0.25
scan_motion_mode: continuous
scan_continuous_step_mm: 150.0
scan_continuous_speed: 200.0
scan_continuous_accel: 2000.0
scan_continuous_poll_interval: 0.05
```

| Setting | Default | Description |
|---|---|---|
| `scan_enabled` | `False` | Controls the automatic Happy Hare gate-status edge trigger. `False` disables automatic 0→1 scan-jog, but manual `NFC JOG_SCAN=1` or Happy Hare hook-triggered `_NFC_SCAN_JOG_PRELOAD` still works. |
| `scan_jog_mm` | `150.0` | Logical filament advance per scan chunk (mm). NFC divides this into three blocking MMU_TEST_MOVE substeps so it can read at stopped spool positions. For rich tags such as Bambu/MIFARE, a smaller value like `75.0` can improve payload-read reliability. |
| `scan_jog_max` | unset | Optional maximum scan-jog travel distance. When set, NFC uses this value and does not read Happy Hare Bowden calibration. `480.0` is roughly one full spool rotation. Leave unset/commented to keep scanning until the active lane's Bowden calibration length is reached. |
| `scan_reads_per_position` | `1` | Number of NFC read attempts at each stopped spool position before moving the next substep. Reads are spaced by `scan_poll_interval`. Increase for marginal tag alignment at the cost of scan time. |
| `scan_rewind_buffer_mm` | `30.0` | Distance reserved for Happy Hare's final gate-parking step (`_MMU_STEP_UNLOAD_GATE`). After a tag is found, NFC fast-rewinds to within this buffer and then hands off to HH for sensor/encoder-based final parking. If the scan moved less than this value, the fast rewind is skipped. |
| `scan_decode_retry_mm` | `5.0` | Distance between nearby retry positions after a UID is found but the rich tag payload is marked incomplete. |
| `scan_decode_retry_rounds` | `5` | Nearby retry rounds before accepting the current UID/metadata result. Each round probes both sides of the first UID hit. |
| `scan_poll_interval` | `0.25` | Seconds between stopped-position NFC read attempts during scan-jog. The shared reader also uses this value as its active polling cadence. Since Happy Hare `MMU_TEST_MOVE` blocks by default, this is not a read-while-moving interval. |
| `scan_motion_mode` | `continuous` | `continuous` (default) uses the lane NFC virtual endstop for the full remaining forward search and records UID hits while the homing move is active. `stopped` uses blocking MMU_TEST_MOVE substeps with reads at each stopped spool position — use this for marginal reader or tag alignment. |
| `scan_continuous_step_mm` | `150.0` | Continuous-mode forward search chunk size. Rich tag reads use the observed UID hit-window center, so this value no longer needs to be kept small just to avoid overshooting the ideal metadata-read position. |
| `scan_continuous_speed` | `200.0` | Continuous-mode gear move speed in mm/s. |
| `scan_continuous_accel` | `2000.0` | Continuous-mode gear move acceleration in mm/s^2. At `150mm`, `200mm/s`, `2000mm/s^2`, each move takes about `0.85s` before NFC read time is included. |
| `scan_continuous_poll_interval` | `0.05` | NFC read cadence while a continuous chunk is estimated to be in flight. When the chunk completes with no tag, NFC queues the next chunk. |

There is no user setting for left-neighbor interference. During scan-jog, gate
`N` first trusts a Spoolman UID hit when it resolves to a different spool than
gate `N - 1`. For rich manufacturer tags that expose a same-spool
`spool_identity` (Bambu `tray_uid`, TigerTag Twin Tag ID, Creality decoded
payload hash), NFC also compares that identity against the cached identity on
gate `N - 1`. If it matches, NFC moves the left neighbor 75 mm out of range,
clears the false read, restarts a full scan on the current lane, and restores
the neighbor on scan exit.

Continuous scan mode preserves the existing tag-found path: tag actions are
cached until after rewind, the 0.1 second read-light hold still plays before the
rewind effect, and `_scan_mm_total` still drives the final rewind distance.
If a continuous scan sees a UID during motion, NFC waits for the chunk to
finish, checks whether Spoolman already knows the UID, and stops the scan if it
does not need a richer identity check. If the UID does not resolve through
Spoolman, or if the resolved spool matches the left neighbor and rich tag
parsing is needed to confirm interference, NFC backs up to the observed UID
hit-window center before rich parsing and the normal `scan_decode_retry_mm`
retry sweep.

When a virtual NFC homing move consumes the full configured scan distance
without caching a UID, NFC rewinds directly. It does not start one extra
endpoint PN532 probe, because the final virtual-endstop discovery may still be
busy. A fixed internal `0.1mm` end tolerance also prevents floating-point
residue from generating a `MOVE=0.00` homing command.

**Happy Hare post-preload hook (alternative to automatic polling):**

The [igiannakas IG-dev branch](https://github.com/igiannakas/Happy-Hare/tree/IG-dev) of Happy Hare adds `variable_user_post_preload_extension` in `config/base/mmu_macro_vars.cfg`. Set it to trigger NFC scan-jog after each successful `MMU_PRELOAD`:

```ini
[gcode_macro _MMU_SEQUENCE_VARS]
description: Happy Hare sequence macro configuration variables
gcode: # Leave empty
variable_user_post_preload_extension: '_NFC_SCAN_JOG_PRELOAD'
```

Happy Hare V3 appends `GATE=<n>` automatically. V4 invokes the hook without
that parameter, so `_NFC_SCAN_JOG_PRELOAD` falls back to `printer.mmu.gate`.
It then calls `NFC GATE=<n> JOG_SCAN=1 SOURCE=AUTO`; the marker permits V4's
trusted post-preload `action=checking` state while manual scan commands remain
restricted to `action=idle`. NFC starts the configured scan-jog LED effect from
the Python scan timer before motion begins. NFC always clears the Happy Hare
gate cache, explicitly unsets the old Spoolman gate assignment with
`MMU_SPOOLMAN GATE=<n>`, and runs the pre-scan `MMU_SPOOLMAN SYNC=1`; when
launched from this hook, those calls are deferred to the scan timer so the hook
can return first.

Recommended NFC config when using the hook:

```ini
[nfc_gate]
startup_polling: 0
scan_enabled:    False
```

With this setup NFC does not poll gate-status at all — Happy Hare calls NFC only after the relevant gate completes preload. The gate-status 0→1 edge trigger is disabled.

---

### PN532 I2C Timing

```ini
[nfc_gate]
i2c_address: 36
i2c_bus:     i2c3_PB3_PB4
startup_poll_delay: 0.5
```

These keys in the base `[nfc_gate]` section are inherited by every `[nfc_gate laneN]`. Set them once here; lane sections only need to specify them if a particular reader differs from the rest.

| Setting | Default | Description |
|---|---|---|
| `i2c_address` | `36` (`0x24`) | PN532 I2C address as a decimal integer. The PN532 I2C address is fixed at `0x24` (36) by the chip — leave this at the default. |
| `i2c_bus` | _(none)_ | Hardware I2C bus identifier on the lane MCU. Must be set in the base section or overridden per lane. |

**Common bus names:**

| Board / wiring | `i2c_bus` value |
|---|---|
| EBB42 v1.x (PB3/PB4) | `i2c3_PB3_PB4` |
| SLB (PB10/PB11) | `i2c2_PB10_PB11` |

> [!NOTE]
> The PN532 I2C address is hardwired to `0x24` (decimal `36`). The two pads/jumpers on the breakout board (SEL0/SEL1, sometimes labeled A0/A1) select the **communication protocol** (I2C, SPI, or HSU), not the address. For I2C: SEL0=1, SEL1=0. See the [PN532 wiring guide](../i2c-nfc/pn532-wiring.md) for the mode selection table.

---

### PN532 Timing

```ini
[nfc_gate]
transceive_delay: 0.250
crc_delay:        0.050
```

These are tuned for CAN bus round-trip latency on the EBB42. Leave them at defaults unless you're debugging timing-related failures.

| Setting | Default | Description |
|---|---|---|
| `transceive_delay` | `0.250` | Seconds to wait after `InListPassiveTarget` before reading the response. The PN532 scans for tags during this window. Increase if you see spurious `i2c_read_response` timeouts. |
| `crc_delay` | `0.050` | Seconds after `InRelease` before the next command. |

---

### Logging

```ini
[nfc_gate]
log_file:          nfc_reader.log
debug:             2
console_output:    False
console_log_level: 2
```

| Setting | Default | Description |
|---|---|---|
| `log_file` | `nfc_reader.log` | Log filename. Relative paths resolve to `~/printer_data/logs/`. Set to an absolute path to write elsewhere. Leave empty to use the main Klipper log only. |
| `debug` | `2` | `0` (or `off`) = no logging. `1` (or `error`) = errors only. `2` (or `warning`) = warnings and errors. `3` (or `info`) = state changes, Spoolman lookups, HH handoff. `4` (or `debug`) = full I2C protocol trace. |
| `console_output` | `False` | Send NFC log messages to the Fluidd/Mainsail console. Errors always appear in the console regardless of this setting. |
| `console_log_level` | `2` | Minimum level to show in console when `console_output: True`. Accepts string (`error`, `warning`, `info`, `debug`) or numeric (`1`-`4`). |

Shared reader console messages and their matching `nfc_reader.log` entries are
defined in [Message Definitions](message_definition.md).

**Recommended for normal printing:**
```ini
console_output:    False
console_log_level: 2
```

**Recommended during setup or debugging:**
```ini
console_output:    True
console_log_level: 3
debug:             3
```

---

### Expert Debug Flag

```ini
[nfc_gate]
low_level_debug: False
```

When `True`, exposes manual low-level reader commands for step-by-step bring-up
debugging. PN532 readers expose I2C `STEP`, `RAW_READ`, `RAW_WRITE`, and ACK
helpers. RC522 readers expose SPI register, antenna, FIFO transceive, and REQA
tag-wake helpers on `NFC` / `NFC_SHARED`.

> [!WARNING]
> These commands bypass the normal state machine. Set back to `False` before printing.

See [Commands & Macros](klipper-functions.md#expert-low-level-debug-commands) and [Expert: Low-Level I2C Debugging](expert-low-level-i2c-debugging.md).

---

## `nfc_reader_hw.cfg` — Lane Hardware

One `[nfc_gate laneN]` section per physical gate. Most lanes only need two lines:

```ini
[nfc_gate lane0]
enabled:   True
mmu_gate:  0
i2c_mcu:   lane0
```

`i2c_address` and `i2c_bus` are inherited from the base `[nfc_gate]` section in `nfc_reader.cfg` and do not need to be repeated here unless a specific lane uses different hardware.

| Key | Required | Description |
|---|:---:|---|
| `enabled` | — | `True` by default. Set `False` to leave a lane template in place without creating I2C hardware, registering `NFC GATE=<n>`, or running reader init. Disabled lanes still appear in `NFC_STATUS` and `NFC_DOCTOR`. |
| `mmu_gate` | Yes | Happy Hare gate number (0-based integer). Gate 0 = first MMU gate. |
| `i2c_mcu` | Yes | Klipper MCU name. Must exactly match an `[mcu laneN]` section in your config. |
| `i2c_bus` | — | Override the base `[nfc_gate]` bus for this lane only. Omit when all readers share the same bus pin. |
| `i2c_address` | — | Override the base address for this lane only. Omit when all readers are at the default `0x24`. |

Any other `nfc_reader.cfg` key can also be overridden per lane. Example — delayed startup and extra logging on one lane only:

```ini
[nfc_gate lane2]
enabled:           True
mmu_gate:           2
i2c_mcu:            lane2
startup_poll_delay: 1.0
debug:              3
```

To keep a future lane in the file without requiring its MCU or reader to exist:

```ini
[nfc_gate lane4]
enabled: False
mmu_gate: 4
i2c_mcu:  mmu4
```

### `[mmu_nfc_endstop laneN]`

`install.sh` writes one of these alongside every enabled `[nfc_gate laneN]`
section. It registers that lane's reader with Happy Hare as a gear-rail
homing endstop (`ENDSTOP=nfc_lane<N>`) — no new hardware, it borrows the same
reader the matching `[nfc_gate laneN]` section owns. This is what lets
scan-jog's forward search stop the instant the tag is detected instead of
jogging a fixed distance and polling afterward. See
[Virtual Endstop](klipper-functions.md#virtual-endstop) for how scan-jog uses it.

V3 registers the endstop on Happy Hare's shared gear rail. V4 registers it on
the drive selected by the reader's global `mmu_gate`. The section name, reader
name, and `endstop_name` may therefore use any naming convention, including
multi-unit layouts; `nfc_gate` and `mmu_gate` define the actual association.

```ini
[mmu_nfc_endstop lane0]
nfc_gate:                lane0
endstop_name:            nfc_lane0
poll_interval:           0.05
register_sensor:         True
```

| Key | Required | Description |
|---|:---:|---|
| `nfc_gate` | Yes | Name of the matching `[nfc_gate laneN]` section this endstop borrows a reader from. |
| `endstop_name` | — | Endstop name Happy Hare homing moves reference as `ENDSTOP=<name>`. Defaults to the section name (`lane0`, `lane1`, ...); the installer writes `nfc_lane0`, `nfc_lane1`, etc. explicitly. |
| `poll_interval` | — | Seconds between NFC reads while a homing move against this endstop is in progress. Default `0.05`. |
| `register_sensor` | — | `True` by default. Also registers this endstop as a `filament_switch_sensor`-style presence sensor so Happy Hare's runout tooling can see it. |

`[mmu_nfc_endstop laneN]` has no `enabled` flag of its own, and it requires
its matching `[nfc_gate laneN]` to be enabled with a working reader — Klipper
raises a config error at startup (`mmu_nfc_endstop <name> references disabled
[nfc_gate <name>]`) if the lane is disabled while its endstop section is
still present. Comment out (or remove) `[mmu_nfc_endstop laneN]` too when
setting `enabled: False` on a lane.

---

## `nfc_macros.cfg` — Event Macros

These macros are called by NFC_Manager when gate state changes. Edit them to adjust Happy Hare command calls for your Happy Hare version. Do not put Happy Hare commands anywhere else.

### `_NFC_SPOOL_CHANGED`

Called when a tag resolves to a spool (either via Spoolman or from tag metadata directly).

Two dispatch paths depending on tag type and Spoolman availability:

**Spoolman path** — tag UID matched a Spoolman record:
```
GATE  SPOOL_ID  UID  [AUTO_CREATED=1]
```

**Metadata path** — tag carries embedded filament data, Spoolman disabled or no match:
```
GATE  UID  [NAME=...]  [MATERIAL=...]  [COLOR=...]  [TEMP=...]
```

Default:
```gcode
{% if params.SPOOL_ID is defined %}
    {% if auto_created %}
    MMU_SPOOLMAN REFRESH=1 QUIET=1
    {% endif %}
    MMU_GATE_MAP GATE={gate} SPOOLID={spool_id} AVAILABLE=1 SYNC=1 QUIET=1
{% else %}
    MMU_GATE_MAP GATE={gate} [NAME=..] [MATERIAL=..] [COLOR=..] [TEMP=..] AVAILABLE=1 QUIET=1
{% endif %}
MMU_GATE_MAP GATE={gate} APPLY=1 QUIET=1
```

`AUTO_CREATED=1` is set when the spool record was just created by `spoolman_auto_create`. The macro runs `MMU_SPOOLMAN REFRESH=1 QUIET=1` first so Happy Hare's Spoolman cache includes the new spool before the gate assignment is sent.

### `_NFC_SPOOL_REMOVED`

Called after `absent_threshold` consecutive missed polls. Parameter: `GATE`.

Default:
```gcode
MMU_GATE_MAP GATE={gate} SPOOLID=-1 AVAILABLE=0 SYNC=1 QUIET=1
MMU_GATE_MAP GATE={gate} APPLY=1 QUIET=1
```

### `_NFC_TAG_NO_SPOOL`

Called when a tag is detected but cannot be resolved to a spool. Parameters:
`GATE`, `UID`, and optional `SPOOLMAN_DISABLED`.

Default: with Spoolman enabled, prints the unknown UID with instructions to
register it. With Spoolman disabled, prints a warning that the tag was read but
no rich metadata or spool assignment was available.

---

---

## Shared Reader

The shared reader is an optional single NFC reader mounted inside the MMU body — not tied to any EMU lane. It defaults to PN532 hardware and also supports PN7160, RC522, and PN5180. Tap a tagged spool on it before loading; when Happy Hare starts the pregate preload NFC stages the spool ID automatically.

**No per-lane readers are required.** A shared-only installation needs only the base `[nfc_gate]` section (for Spoolman config) and the `[nfc_gate shared]` section. No `[nfc_gate lane0]` or similar sections are needed.

The shared reader lives in its own file — `nfc_reader_shared.cfg` — so it can be added to any install without editing the lane hardware config. For a **pure shared install**, include it instead of `nfc_reader_hw.cfg`. For a **hybrid install** (per-lane readers plus a shared reader), include both.

Run `install.sh` to generate `nfc_reader_shared.cfg` with your hardware values, or copy the template from `config/nfc_reader_shared.cfg` in the repo and edit the I2C or SPI settings required by the selected `reader_type`.

### Config

The `[nfc_gate shared]` section lives in `nfc_reader_shared.cfg`:

```ini
[nfc_gate shared]
enabled:                True
i2c_mcu:                mmu
shared:                 true
startup_polling:        1
```

Full config with all optional keys shown:

```ini
[nfc_gate shared]
enabled:                True
i2c_mcu:                mmu
shared:                 true
startup_polling:        1
shared_read_timeout:    120.0
shared_tag_read_effect: mmu_RFID_read
read_effect_duration:   2.0
shared_bypass_tag_read_effect: mmu_RFID_bypass_read
bypass_read_effect_duration:   2.0
shared_spool_ready_effect: mmu_RFID_ready
shared_bypass_spool_ready_effect: mmu_RFID_bypass_ready
bypass_ready_effect_duration: 2.0
shared_tag_unresolved_effect: mmu_RFID_unresolved
unresolved_effect_duration: 2.0
shared_spool_warning_effect: mmu_RFID_warning
shared_auto_create_effect:   mmu_RFID_creating
shared_missed_limit:    3
force_spool_id:         true
```

| Setting | Default | Description |
|---|---|---|
| `enabled` | `True` | Set `False` to keep the shared-reader template installed without initializing hardware or registering `NFC_SHARED`. |
| `shared` | `false` | Enable shared dispatch for this reader. Must be `true`. |
| `startup_polling` | `1` in the shipped template | Set to `1` to poll at Klipper boot. Set to `0` or `-1` if you want to start it manually with `NFC_SHARED READ=1`. |
| `scan_poll_interval` | inherited from `[nfc_gate]` | Seconds between shared-reader tag reads while polling. The shipped default is `0.25`. |
| `poll_interval` | inherited from `[nfc_gate]` | Ignored for shared-reader read cadence; lane readers still use it for normal background polling. |
| `pending_spool_id_timeout` | set in `mmu_parameters.cfg` | Seconds a scanned spool remains eligible for the next preload. NFC reads this from Happy Hare's `[mmu]` section at connect time (falls back to 30 s). Set it in `~/printer_data/config/mmu/base/mmu_parameters.cfg`. |
| `shared_read_timeout` | `120.0` | Seconds polling may run without resolving a valid tag before auto-stopping. No effect when started via `startup_polling` or PRELOAD_CHECK auto-restart. |
| `shared_tag_read_effect` | `''` | Name of a `[mmu_led_effect]` to play as soon as the shared reader sees a tag. Leave empty to skip tag-detected LED feedback. |
| `read_effect_duration` | `2.0` | HH duration used by `NFC_SHARED LED_TEST=1`. Normal shared scans do not pass this duration to HH; NFC uses it only as a failsafe release window if no follow-up state replaces the read cue. |
| `shared_bypass_tag_read_effect` | `mmu_RFID_bypass_read` | Name of a `[mmu_led_effect]` to play when a tag is seen while Happy Hare bypass is selected. |
| `bypass_read_effect_duration` | `2.0` | Reserved for standalone bypass-read feedback. Normal bypass reads stay interruptible because bypass-ready feedback is expected to follow. |
| `shared_spool_ready_effect` | `''` | Name of a `[mmu_led_effect]` to play when the tag resolves to a Spoolman spool and is ready to load. Normal staged-spool ready feedback runs until preload commit, cancel, replace, or pending timeout; NFC then releases HH ownership with `MMU_GATE_MAP QUIET=1`. |
| `shared_bypass_spool_ready_effect` | `mmu_RFID_bypass_ready` | Name of a `[mmu_led_effect]` to play when a bypass spool resolves. |
| `bypass_ready_effect_duration` | `2.0` | Seconds before NFC stops `shared_bypass_spool_ready_effect`. |
| `shared_tag_unresolved_effect` | `''` | Name of a `[mmu_led_effect]` to play when the tag UID does not resolve to a spool. Leave empty to skip unresolved LED feedback. |
| `unresolved_effect_duration` | `2.0` | Seconds before NFC stops `shared_tag_unresolved_effect`. For example, `layers: strobe 2 2 ...` plus `unresolved_effect_duration: 1.0` plays two flashes and stops after 1 second. |
| `shared_spool_warning_effect` | `mmu_RFID_warning` | Name of a `[mmu_led_effect]` to play when the staged spool reaches 80% of its pending timeout. NFC does not pass HH `DURATION`; the effect must remain interruptible when preload starts. |
| `shared_auto_create_effect` | `mmu_RFID_creating` | Name of a `[mmu_led_effect]` to play while Spoolman auto-create is running. |
| `shared_missed_limit` | `3` | Consecutive unresolvable UID reads before a console error advises the user to use `MMU_PRELOAD`. Minimum 1. |
| `force_spool_id` | `true` | When `true`, `PRELOAD_CHECK` emits a `[ERROR]` advisory if no spool is staged, telling the user to scan a tag before loading. |

`mmu_gate` and `scan_enabled` are not user-configurable — both are set internally by `shared: true`. Only one enabled shared reader may be configured. The reader inherits `spoolman_url`, `spoolman_rfid_key`, `tag_parsing`, `spoolman_auto_create`, and all logging settings from the base `[nfc_gate]` section. Set `enabled: False` to keep the shared-reader template installed without initializing hardware.

`MMU_SET_LED DURATION=` is intentionally limited to standalone or timeout-bound LED feedback. Happy Hare sets a per-unit pending-update flag while a duration timer is active, and later LED effect calls for that unit are ignored until the timer expires. Normal shared read and staged-ready effects do not pass `DURATION` so follow-up shared-reader states can replace them immediately.

For normal shared reads, `read_effect_duration` still provides a local failsafe:
if the read LED starts and no follow-up state takes ownership, NFC releases the
LEDs back to Happy Hare with `MMU_GATE_MAP QUIET=1`.

**Rich tags** work with the shared reader only when they resolve to a real
Spoolman spool ID. That can happen through an existing UID lookup, an embedded
`spoolman_id`, or `spoolman_auto_create: true`. Metadata-only rich tags are not
enough for shared preload staging because `MMU_GATE_MAP NEXT_SPOOLID` requires
an integer spool ID. See [Shared Reader — Rich tag compatibility](shared-reader.md#rich-tag-compatibility).

### Happy Hare hook wiring

Add one user extension hook to `mmu_macro_vars.cfg`:

```ini
[gcode_macro _MMU_SEQUENCE_VARS]
; stage NEXT_SPOOLID before a pregate-triggered automatic preload
variable_user_post_preload_extension: '_NFC_SHARED_PRELOAD'
```

`variable_user_post_preload_extension` fires at the start of every pregate load. `PRELOAD_CHECK` skips only while printing — it is safe to leave wired for all loads. If no spool is staged a console message advises the user; with `force_spool_id: true` that advisory uses the `[ERROR]` prefix.

Shared polling pauses automatically when printing starts and resumes when printing completes via Klipper's `idle_timeout` events — no post-unload hook is needed.

The post-preload hook points to a macro shipped in `nfc_macros.cfg`. Override it in your own cfg to add logic around the NFC check without changing the HH variable.

### LED effect

Define a named `[mmu_led_effect]` in your LED config (same style as `emu_macros.cfg`):

```ini
[mmu_led_effect mmu_RFID_read]
define_on: gates
layers: strobe 1 2 top (1, 1, 0)

[mmu_led_effect mmu_RFID_ready]
define_on: gates
layers: strobe 1 2 top (0, 1, 0)

[mmu_led_effect mmu_RFID_unresolved]
define_on: gates
layers: strobe 2 2 top (1, 0, 0)
```

The effect names must match `shared_tag_read_effect`, `shared_spool_ready_effect`, and `shared_tag_unresolved_effect` in the gate config.

`shared_auto_create_effect: mmu_RFID_creating` runs a bright yellow chase while Spoolman creates a missing spool, then stops before the green ready blink.

---

*Copyright (C) 2026 WoodWorker. Licensed under [GPL-3.0-or-later](https://www.gnu.org/licenses/gpl-3.0.html) — see [LICENSE](../../LICENSE).*

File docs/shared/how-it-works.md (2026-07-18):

# How It Works

[← README](../../Readme.md)

---

## Startup — Boot Sequence

When Klipper connects, each lane goes through this sequence before polling begins:

```
klippy:connect
  └─ NFC_Manager registers commands
  └─ schedules _delayed_init()  (2 s delay — lets I2C and HH settle)

_delayed_init()
  └─ initialises NFC reader
  └─ reads Happy Hare gate map  ← seeds local lane cache from HH state
  └─ starts background polling  (if startup_polling: 1)
```

### Why seed from Happy Hare?

After a Klipper restart the NFC lane cache is empty — but Happy Hare already knows which spool is in each gate from its own persisted state. Without seeding, the first poll would detect the tag, resolve it through Spoolman, and fire `_NFC_SPOOL_CHANGED` — redundantly telling Happy Hare something it already knows. With seeding, that first poll is absorbed silently.

If the physical spool was swapped while Klipper was down, the resolved spool_id won't match the seed, and `_NFC_SPOOL_CHANGED` dispatches normally.

### Startup console output

```
[OK] NFC[lane0]: ready.  HH seed: spool_id=42  Startup polling is enabled; first poll in 0.0s.
[OK] NFC[lane1]: ready.  HH reports gate empty  Run NFC GATE=1 READ=1 to start polling.
```

The seed is one-shot — it fires at most once per lane per boot, on the first `CHANGED` event. If Happy Hare wasn't ready when the NFC init ran, the seed step is skipped and a manual `NFC_HH_SYNC_CACHE` re-syncs all lanes.

---

## Per-Poll Flow

Tags are never written to. The NFC tag's factory UID is stored as a Spoolman extra field (`rfid_tag` by default). On every poll:

```
NFC reader reads tag UID (or detects absence)
        │
        ▼
SpoolmanClient resolves UID → spool_id
(in-memory cache if fresh · HTTP query if expired or cleared)
        │
        ▼
NFC_Manager compares (uid, spool_id) against the lane cache
Both must match to be considered unchanged
        │
        ▼
State changed?
  ├─ New / re-assigned spool  →  _NFC_SPOOL_CHANGED  GATE=n  SPOOL_ID=id  UID=uid
  ├─ Tag absent (threshold)   →  _NFC_SPOOL_REMOVED  GATE=n
  └─ UID not in Spoolman      →  _NFC_TAG_NO_SPOOL   GATE=n  UID=uid
        │
        ▼
nfc_macros.cfg calls MMU_GATE_MAP ... to Happy Hare
```

The `(uid, spool_id)` combination check means that if the same physical tag is re-registered to a different spool in Spoolman, the change is detected on the next poll after the cache expires (or after `CLEAR_CACHE=1`).

---

## Scan-and-Jog Flow

When a spool is loaded, the NFC tag is on the hub face — it may be pointing any direction. The scan-jog loop rotates the spool until the tag comes within read range of the NFC reader antenna.

During this scan, the current gate also checks for a narrow physical edge case:
antenna crosstalk from the adjacent gate's reader. This applies to rich tag
formats that can identify the same spool independently of the chip's factory
UID. Bambu (`tray_uid`), TigerTag/TigerTag+ (Twin Tag ID), and Creality
(decoded payload hash) all expose a parser-derived `spool_identity` for this.

The scan-jog resolution ladder is:

1. Capture the hardware UID.
2. Ask Spoolman whether that UID already belongs to a spool.
3. If the UID resolves to a different spool than the left neighbor's cached
   spool, accept the Spoolman result immediately.
4. If rich parsing is needed, read the manufacturer payload and compute
   `spool_identity`.
5. Before auto-creating or accepting a metadata-only result, compare the
   current `spool_identity` with gate `N - 1`'s cached `spool_identity`.

If both identities match, the read is treated as left-neighbor interference.
NFC briefly shifts the left neighbor out of the reader field, clears the false
read, restarts a full scan on gate `N`, and restores the neighbor when the scan
exits. Tag formats without a parser-derived `spool_identity` do not use this
same-spool interference check; raw material/color/brand metadata is not reliable
proof of same-vs-different spool on its own.

### Trigger

The poll tick runs the gate-status edge check on every cycle. When all conditions are met, scan mode starts and the poll timer parks itself at `NEVER` for the duration.

```
_poll_timer_event  (every poll_interval seconds)
  └─ reads HH gate_status[N]  (Python dict — no I2C)
  └─ gate_status was 0, is now 1?
       AND  HH action == idle?
       AND  not printing?
       AND  no other gate currently scanning?
         └─ YES → _start_scan_mode()  →  poll timer parks at NEVER
         └─ NO  → continue normal polling
```

Initialization sets `_prev_gate_status = -1` so a cold-start with status already at 1 (from a previous session) does not trigger scan mode — only a fresh 0→1 transition fires it.

### Virtual endstop

`mmu_nfc_endstop.py` wraps a lane's existing `[nfc_gate laneN]` reader as a
Happy Hare gear-rail endstop (`ENDSTOP=nfc_lane<N>`) — no extra hardware. While
Happy Hare is homing against it, a reactor timer polls the lane's NFC reader
every `poll_interval` (default `0.05s`) and reports the endstop triggered the
instant a tag UID is read. Both scan-jog motion modes use this: the forward
search is a real Klipper homing move for the full remaining scan distance
(`_MMU_STEP_HOMING_MOVE ENDSTOP=nfc_lane<N> STOP_ON_ENDSTOP=1 MOTOR=gear`, or
the direct `mmu.move_filament(homing_move=1, endstop_name=...)` equivalent
when available), which physically stops the instant the tag is detected —
scan-jog gets the tag's real position from the homing result, not from an
estimate after a fixed-length jog.

The registration is version-aware. On Happy Hare V3 the endstop is added to
the legacy shared gear rail. On V4 it is added to the gear rail for the drive
selected by the reader's global `mmu_gate`. This lets one NFC configuration
serve V3, V4, and multi-unit V4 layouts without relying on `laneN` naming.

### Scan loop

```
_scan_step_event  (stopped mode)
  └─ print started?  →  rewind and exit
  └─ homing move for the remaining scan distance, ENDSTOP=nfc_lane<N>
       (stops early the instant the virtual endstop trips)
  └─ _poll()
       └─ tag found?  →  _finish_scan()
            └─ dispatch spool to Happy Hare (already done inside _poll)
            └─ rewind to parked position, hand final parking to Happy Hare
            └─ resume poll timer
  └─ scan_mm_total >= scan_jog_max or lane Bowden length?  →  rewind and exit (no tag found)
```

`_poll()` during a scan step is identical to a normal poll — I2C read, Spoolman lookup, `GateState.process_read`, macro dispatch. The only difference is that `GateState.miss_count` does not increment on a no-read during scan (a blank read while the spool rotates is not an absence event).

`scan_motion_mode: continuous` is the default. It changes only how NFC reacts
while the homing move is in flight — tag-found actions, the 0.1 second
read-light hold, rewind, and completion logic are identical in both modes.

`scan_motion_mode: stopped` is the alternative: it waits for the homing move
to finish (or fail to trigger, at which point NFC rewinds with no tag found),
then reads once. Use this for marginal reader or tag alignment where the
in-flight continuous probing below misses the tag.

Continuous mode additionally polls the reader *while* the homing move is
still moving, building a UID hit-window (the mm range where the UID was
observed) used later to recenter before rich tag parsing:

```
_scan_step_event  (continuous mode)
  └─ print started? → rewind and exit
  └─ homing move for the remaining scan distance, ENDSTOP=nfc_lane<N> (in flight)
       └─ UID found while still moving? → keep probing, record hit-window, wait for move to finish
  └─ move complete →
       └─ Spoolman UID lookup succeeds? → existing _finish_scan()
       └─ UID unresolved and rich parsing enabled? → back up to UID hit-window center
       └─ rich payload incomplete? → retry around backed-up position
       └─ tag found → existing _finish_scan()
            └─ 0.1 second read-light hold
            └─ rewind
            └─ dispatch cached tag/spool event
  └─ scan limit reached with no tag? → rewind and exit
```

For a full-travel NFC homing move with no cached UID, scan-jog rewinds directly
instead of issuing a second endpoint probe. The virtual endstop owns the final
PN532 discovery and that request may still be busy. A `0.1mm` internal end
tolerance also suppresses zero-distance homing commands caused by position
rounding.

The shipped continuous config probes at 200 mm/s and 2000 mm/s^2 with a
0.05 s in-flight read cadence. During in-flight motion NFC uses a UID-only
probe and avoids rich tag parsing. Once the homing move completes, Spoolman
UID lookup runs first; if it resolves, scan-jog can finish without any rich
read. If the UID does not resolve and rich parsing is enabled, NFC backs up
to the observed UID hit-window center before rich parsing. After that
one-time recenter move, decode retry moves for incomplete rich tag reads stay
on the existing stopped/blocking retry path. Continuous mode's rewind leg
still uses a queued Happy Hare MMU-toolhead move (bypassing the public
`MMU_TEST_MOVE` G-code wrapper) rather than a homing move, since there is no
tag to home against on the way back.

### Class-level scan lock

All lane instances share one class variable, `NFCGate._active_scan_gate`. Because Klipper's reactor is single-threaded, reads and writes are atomic with respect to timer callbacks — no mutex needed. Only one gate may scan at a time; a second gate that detects a 0→1 edge while the lock is held re-arms its pending flag and retries on the next poll tick. The lock is held until a scan's rewind, Happy Hare dispatch, poll resume, and LED release have all completed — releasing it any earlier let a second `JOG_SCAN=1` start while the previous session's own Happy Hare interaction was still in flight.   If you try to start a jog_scan while another is in flight, and that attempt is blocked/queued for next tick, you may see a spool start jogging wihtout an interactive initiation.   This behavior is expected, as it's the queued scan executing once the block is lifted.   The behavinor allows the user to add spools to the mmu without having to wait for a previous jog_scan to complete.  as each laned completes, the next lane will initiate the jog_scan.

---

## System Layers

Each layer owns one responsibility and must not reach across the boundary.

| Layer | File | Owns | Does not own |
|---|---|---|---|
| **ReaderFactory** | `reader_factory.py` | Selects `PN532Driver`, `PN7160Driver`, `RC522Driver`, or `PN5180Driver` from `reader_type`, validates reader-specific bus defaults | Tag parsing, gate policy, Happy Hare |
| **PN532Driver** | `pn532_driver.py` | PN532 wire protocol, I2C frames, UID/page/block reads | Spoolman, gate policy, Happy Hare |
| **PN7160Driver** | `pn7160_driver.py` | PN7160/NCI protocol, Type2/Type5/MIFARE reads, RF discovery lifecycle | Spoolman, gate policy, Happy Hare |
| **RC522Driver** | `rc522_driver.py` | RC522 SPI register protocol, ISO14443A select/cascade, UID reads, NTAG/Type-2 page reads, and MIFARE Classic auth/block reads | Rich tag parsing, Spoolman, gate policy, Happy Hare |
| **PN5180Driver** | `pn5180_driver.py` | PN5180 SPI protocol, BUSY-synchronized commands, hardware-reset recovery, ISO14443A/NTAG/MIFARE and SLIX2 (ISO15693) reads | Rich tag parsing, Spoolman, gate policy, Happy Hare |
| **SpoolmanClient** | `spoolman_client.py` | UID → spool record lookup, TTL cache, URL discovery | Gate state, lane assignment, MMU commands |
| **TagHandler** | `tag_handler.py` | Tag classification, NTAG/MIFARE capture, metadata parsing, spool resolution ladder | Gate lifecycle, polling timers, GCode dispatch |
| **GateState** | `gate_state.py` | Per-gate debounce state machine, event generation, `CurrentTag` observation | Hardware reads, Spoolman, GCode |
| **KlipperInterface** | `klipper_interface.py` | GCode macro dispatch (reactor-thread safe), macro string building | Gate state, hardware, Spoolman |
| **NFCGate / NFCGateDefaults** | `nfc_manager.py` | Config, polling lifecycle, HH seed, scan-jog coordination | Reader wire protocol, Spoolman HTTP |
| **nfc_macros.cfg** | config file | Happy Hare-facing GCode calls | NFC reads, Spoolman lookups |

---

## Macro Dispatch Events

NFC_Manager fires exactly one of these on a state change. They live in `nfc_macros.cfg` and are the only place Happy Hare commands are called.

| Macro | When | Parameters |
|---|---|---|
| `_NFC_SPOOL_CHANGED` | Tag resolved to a spool (Spoolman or metadata-direct) | `GATE`, `UID`; plus `SPOOL_ID` (Spoolman path) or `NAME`/`MATERIAL`/`COLOR`/`TEMP` (metadata path, each optional); `AUTO_CREATED=1` when spool was just created |
| `_NFC_SPOOL_REMOVED` | Tag absent for `absent_threshold` consecutive polls | `GATE` |
| `_NFC_TAG_NO_SPOOL` | Tag read but UID not registered in Spoolman | `GATE`, `UID` |

The default macro body for `_NFC_SPOOL_CHANGED` handles both paths:
```gcode
{% if params.SPOOL_ID is defined %}
    {% if params.AUTO_CREATED is defined %}
    MMU_SPOOLMAN REFRESH=1 QUIET=1
    {% endif %}
    MMU_GATE_MAP GATE={gate} SPOOLID={spool_id} AVAILABLE=1 SYNC=1 QUIET=1
{% else %}
    MMU_GATE_MAP GATE={gate} [NAME=..] [MATERIAL=..] [COLOR=..] [TEMP=..] AVAILABLE=1 QUIET=1
{% endif %}
MMU_GATE_MAP GATE={gate} APPLY=1 QUIET=1
```

You can edit `nfc_macros.cfg` to match your Happy Hare version without touching any Python.

---

*Copyright (C) 2026 WoodWorker. Licensed under [GPL-3.0-or-later](https://www.gnu.org/licenses/gpl-3.0.html) — see [LICENSE](../../LICENSE).*

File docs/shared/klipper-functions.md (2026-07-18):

# Commands & Macros

[← README](../../Readme.md) | [Configuration](configuration.md) | [Messages →](message_definition.md)

This is the day-to-day reference for operating the NFC gate reader from the Fluidd/Mainsail console.

For shared reader console and `nfc_reader.log` messages, see [Message Definitions](message_definition.md).

---

## Quick Reference

| Command | What it does |
|---|---|
| `NFC_HELP` | Show global NFC command help; add `ADVANCED=1 CALLBACKS=1 LOW_LEVEL=1` for the full command set |
| `NFC_STATUS` | Show current state of every configured gate (includes shared reader if configured) |
| `NFC_DOCTOR` | Check common config/setup problems: disabled lanes, Spoolman, shared-reader hook, and static warnings |
| `NFC_REGISTER UID=TAG_UID SPOOL_ID=SPOOL_ID` | Assign a known NFC UID to an existing Spoolman spool and clear NFC's lookup cache |
| `NFC_LED_TEST ALL=1` | Test lane tag-read LEDs across every enabled per-lane reader with a short chase delay |
| `NFC GATE=<#> STATUS` | Show one gate's state |
| `NFC GATE=<#> INIT=1` | Initialize (or re-initialize) the NFC reader |
| `NFC GATE=<#> SCAN=1` | One raw read — shows UID, no Spoolman lookup |
| `NFC GATE=<#> LED_TEST=1` | Test the configured lane tag-read LED effect on one gate |
| `NFC GATE=<#> JOG_SCAN=1` | Start scan-jog sequence (same as automatic pre-load trigger) |
| `NFC GATE=<#> POLL=1` | Full cycle: read → Spoolman → Happy Hare |
| `NFC GATE=<#> APPLY=1` | Force cached spool assignment to Happy Hare |
| `NFC GATE=<#> CLEAR_CACHE=1` | Clear cached spool, force fresh Spoolman lookup |
| `NFC GATE=<#> READ=1` | Start background polling |
| `NFC GATE=<#> READ=0` | Stop background polling |
| `NFC GATE=<#> HELP` | Show available commands for one per-lane reader |
| `NFC_HH_SYNC_CACHE` | Re-seed all lane caches from the current Happy Hare gate map |
| `NFC GATE=<#> HH_SYNC=1 SPOOL_ID=<n>` | Seed one lane's cache directly (called by `NFC_HH_SYNC_CACHE`) |
| `NFC_SHARED READ=1` | Start shared polling manually; rejected while printing |
| `NFC_SHARED READ=0` | Stop shared polling (keeps any pending spool) |
| `NFC_SHARED STATUS=1` | Show detailed shared reader state |
| `NFC_SHARED SUMMARY=1` | Show one-line shared reader state and next action |
| `NFC_SHARED HELP=1` | Show shared reader command help |
| `NFC_SHARED CANCEL=1` | Cancel a staged shared spool and stop polling |
| `NFC_SHARED REPLACE=1` | Discard a staged spool and scan another |
| `NFC_SHARED RESET=1` | Clear shared state, restore HH LED control, and restart polling |
| `NFC_SHARED LED_TEST=1` | Test configured shared tag-read LED effect |
| <span style="color:orange">━━━ **Advanced Shared Reader** — internal/recovery commands, not low-level PN532 debug ━━━</span> | |
| `NFC_SHARED CLEAR=1` | Clear pending spool, stop polling, reset shared state |
| `NFC_SHARED PRELOAD_CHECK=1` | Approve the pending shared-reader spool for the HH preload hook |
| `NFC_SHARED PRELOAD_COMMIT=1 SPOOL_ID=<id>` | Clear pending state after the hook bridge accepts the staged spool |
| `NFC_SHARED PRELOAD_CLEAR_ASSIGNED=1 SPOOL_ID=<id>` | Legacy/recovery command to clear shared pending state when HH already has this spool assigned |
| `NFC_SHARED POLL=1` | Force one full read/resolve cycle on the shared reader; skips while printing |
| `NFC_SHARED SCAN=1` | Raw hardware scan only — no Spoolman/HH dispatch; skips while printing |
| `NFC_SHARED INIT=1` | Re-run NFC reader init on the shared reader; resumes startup polling if enabled |
| `NFC_SHARED CLEAR_CACHE=1` | Clear tag cache on the shared reader (keeps pending spool) |
| <span style="color:red">━━━ **Low-Level Debug** — requires `low_level_debug: True` — bypasses normal state machine ━━━</span> | |
| `NFC GATE=<#> STEP=WAKEUP` | Write `0x00` to nudge PN532 out of power-down |
| `NFC GATE=<#> STEP=READY` | Read STATUS byte — expects `01` (ready) |
| `NFC GATE=<#> STEP=FIRMWARE_WRITE` | Send `GetFirmwareVersion` command frame |
| `NFC GATE=<#> STEP=FIRMWARE_ACK` | Read ACK — expects `01 00 00 FF 00 FF 00` |
| `NFC GATE=<#> STEP=FIRMWARE_READY` | Poll STATUS until `01` |
| `NFC GATE=<#> STEP=FIRMWARE_RESPONSE` | Read and parse firmware response |
| `NFC GATE=<#> STEP=FIRMWARE_ACK_DIRECT DELAY=0.050` | Write firmware command and read ACK with configurable delay (timing probe) |
| `NFC GATE=<#> STEP=SAM_WRITE` | Send `SAMConfiguration` command frame |
| `NFC GATE=<#> STEP=SAM_ACK` | Read ACK |
| `NFC GATE=<#> STEP=SAM_READY` | Poll STATUS until `01` |
| `NFC GATE=<#> STEP=SAM_RESPONSE` | Read and parse SAM response |
| `NFC GATE=<#> STEP=PASSIVE_WRITE` | Send `InListPassiveTarget` command frame |
| `NFC GATE=<#> STEP=PASSIVE_ACK` | Read ACK |
| `NFC GATE=<#> STEP=PASSIVE_READY` | Poll STATUS until `01` |
| `NFC GATE=<#> STEP=PASSIVE_RESPONSE LEN=30` | Read raw tag-detect response |
| `NFC GATE=<#> READY_READ=1` | Read PN532 STATUS byte (`01`=ready, `00`=busy) |
| `NFC GATE=<#> ACK_READ=1 LEN=7` | Read STATUS then ACK frame |
| `NFC GATE=<#> RAW_READ=1 LEN=<n>` | Read exactly N raw bytes |
| `NFC GATE=<#> RAW_WRITE=<hex>` | Write raw bytes (no framing added) |
| `NFC GATE=<#> RAW_CMD=<hex>` | Build and send a complete PN532 command frame |

---

## Help Commands

Use `NFC_HELP` the same way you use Happy Hare's `MMU_HELP`: run it by itself
for the everyday command list, or add flags to include less-common sections.

```gcode
NFC_HELP
NFC_HELP ADVANCED=1 CALLBACKS=1 LOW_LEVEL=1
```

`NFC_HELP` shows shared-reader commands only when `[nfc_gate shared]` is
configured. Per-reader help is still available for focused command lists:

```gcode
NFC GATE=0 HELP
NFC_SHARED HELP=1
```

Klipper requires `=1` on shared action flags, so use `NFC_SHARED CANCEL=1`,
not `NFC_SHARED CANCEL`.

---

## Startup — Happy Hare Cache Seed

When Klipper connects, NFC_Manager runs this sequence for each lane automatically:

```
klippy:connect  →  _handle_connect()  →  schedule _delayed_init() (2 s)

_delayed_init()
  1. Initialise NFC reader
  2. Read Happy Hare gate map  →  seed this lane's local cache
  3. If Spoolman is disabled, schedule a delayed unknown-gate check
  4. Start background polling  (if startup_polling: 1)
```

When Spoolman is disabled and Happy Hare still reports this lane as unknown
(`gate_status=-1`) after the delayed timer, NFC runs
`MMU_CHECK_GATE GATE=<n>`. NFC uses an internal delayed/staggered timer so lanes
do not all check at once. The check is skipped while printing, while Happy Hare
is busy, or while filament is not parked.

**Step 2 is the key one.** NFC_Manager calls `mmu.get_status()` directly to read `gate_spool_id` for this gate. The result is stored as a one-shot seed. On the very first poll:

- Tag resolves to the **same spool** as the HH seed → cache updated silently, **no dispatch** (HH already knows)
- Tag resolves to a **different spool** → `_NFC_SPOOL_CHANGED` dispatched normally (spool was swapped while Klipper was down)
- No tag present → seed kept until the first successful tag read

The seed is always cleared after the first `CHANGED` event — it fires at most once per startup per lane.

**Console output at startup:**
```
[OK] NFC[lane0]: ready.  HH seed: spool_id=42  Startup polling is enabled; first poll in 0.0s.
[OK] NFC[lane1]: ready.  HH reports gate empty  Run NFC GATE=1 READ=1 to start polling.
```

**If Happy Hare wasn't ready** when the NFC init ran (rare — both init at `klippy:connect`), the seed step is skipped and all first-poll reads dispatch normally. Run `NFC_HH_SYNC_CACHE` to manually re-seed.

---

## `NFC_HH_SYNC_CACHE`

Re-seeds all NFC lane caches from the current Happy Hare gate map. Use this any time you want to re-align NFC state with HH without restarting Klipper.

```gcode
NFC_HH_SYNC_CACHE
```

The macro reads `printer.mmu.gate_spool_id` for each gate and calls `NFC GATE=N HH_SYNC=1 SPOOL_ID=<n>` per lane. The Python side receives the spool_id and sets the seed. On the next poll for each lane, if the physical tag matches the seed, the dispatch is suppressed.

**When to use:**
- Happy Hare wasn't fully initialised when the NFC reader init ran and the startup seed was skipped
- You manually changed the HH gate map and want NFC to treat the current state as baseline
- After loading filament manually (without NFC) and you don't want a spurious CHANGED on the next poll

---

## Normal Operation

### `NFC_STATUS`

Shows the NFC_Manager's last known state for every gate. This is an in-memory snapshot — it is not a live I2C read.

```gcode
NFC_STATUS
```

Example output:
```
NFC gate status  (5 gates configured):
  Gate 0:  empty   [not polling]  [HH: empty]
  Gate 1:  empty   [polling]  [HH: empty]
  Gate 2:  tag 6317B1A1  metadata material=PLA color=FFFFFF spool_identity=bambu_BB9B88E7ED544C1B8FAA92972900E77B   [not polling]  [HH: found/no spool]
  Gate 3:  tag 04C19F92  metadata material=PLA color=FF5500 spool_identity=None   [not polling]  [HH: found/no spool]
  Gate 4:  spool 43     UID 04456192D32A81   [polling]  [HH: spool 43]
```

For metadata-direct tags, `spool_identity` is the parser's optional
spool-level identity. It is distinct from the physical NFC tag UID, and only
set for tag formats that ship two physical tags per spool (one on each
side): Bambu factory spools derive it from `tray_uid` as
`bambu_<tray_uid>`, and TigerTag/TigerTag+ spools derive it from the
tag's Twin Tag ID field as `tigertag_<twin_tag_id>`. Either way, the two
physical side tags on the same spool can have different UIDs while sharing
the same `spool_identity`. Every other supported format is single-tag and
has no `spool_identity` — those display `spool_identity=None`.

---

### `NFC_DOCTOR`

Runs a no-motion setup check. It does not scan tags or move filament.

```gcode
NFC_DOCTOR
```

It reports enabled/disabled lane readers, shared-reader state, detected Happy
Hare version, Spoolman availability, the shared-reader preload hook, and static
config warnings such as `bambu_reads: True` without `tag_parsing: True`.
Doctor also prints the scan-jog action rule for the detected Happy Hare version:
v4 accepts `action=idle` or `action=checking`; v3/pre-v4 and unknown versions
accept only `action=idle`.

---

### `NFC_REGISTER UID=TAG_UID SPOOL_ID=SPOOL_ID`

Writes a known tag UID to an existing Spoolman spool using the configured
`spoolman_rfid_key` field. This is for cases where you already know the UID
from a phone scan, a raw NFC scan, or an unresolved-tag console message and you
do not want to open the browser-based Spoolman UI.

```gcode
NFC_REGISTER UID=04A1B2C3D4 SPOOL_ID=123
```

The command validates that Spoolman is enabled, confirms the spool exists,
writes the UID to Spoolman, and clears NFC's UID lookup cache. It does not scan
every spool for duplicate UIDs and does not call `MMU_SPOOLMAN REFRESH` from
inside the command path. Happy Hare and Fluidd see the updated field through
their normal Spoolman refresh/polling behavior.

Expected success:
```
[OK] NFC: UID 04A1B2C3D4 assigned to Spoolman spool 123; NFC cache cleared. Happy Hare/Fluidd will refresh on their normal Spoolman polling cycle.
```

---

### `NFC GATE=<#> STATUS`

Same as `NFC_STATUS` but for a single lane.

```gcode
NFC GATE=4 STATUS
```

---

### `NFC GATE=<#> INIT=1`

Runs the configured NFC reader's initialization sequence.

```gcode
NFC GATE=0 INIT=1
```

**When to use:** After first wiring, after a failed startup, or after flashing lane MCU firmware.

Expected success:
```
NFC[lane0]: reader OK
```

If this fails, see [Troubleshooting](../i2c-nfc/troubleshooting.md).

---

### `NFC_LED_TEST ALL=1`

Tests the configured per-lane tag-read LED effect on every enabled lane reader,
with a short delay between gates so the effect chases across the MMU. This uses
`scan_tag_read_effect` from `nfc_reader.cfg` and calls Happy Hare with the
base effect plus `GATE=<gate>`. Each cycle starts the effect, waits about two
seconds, then starts the next cycle without restoring gate status in between.
After the final cycle, NFC asks Happy Hare to repaint the gate map so the
active test effects stop. If `CYCLES` is omitted, the default is `2`.

```gcode
NFC_LED_TEST ALL=1
```

The default chase delay is `0.20` seconds and the default cycle count is `2`.
Override either value if needed:

```gcode
NFC_LED_TEST ALL=1 DELAY=0.10 CYCLES=3
```

Expected success:
```
[OK] NFC: lane LED chase test scheduled for gates 0, 1, 2, 3, 4 (delay=0.20s cycles=2)
```

---

### `NFC GATE=<#> SCAN=1`

Reads the PN532 hardware once and prints the raw tag UID. Does not look up Spoolman and does not update Happy Hare.

```gcode
NFC GATE=0 SCAN=1
```

**When to use:**
- Getting a UID to register in Spoolman
- Confirming a reader can physically see a tag
- Checking whether a wiring or mode problem is fixed

---

### `NFC GATE=<#> LED_TEST=1`

Tests the configured tag-read LED effect for one lane reader. If `CYCLES` is
omitted, the default is `2`.

```gcode
NFC GATE=0 LED_TEST=1 CYCLES=2
```

With the default `scan_tag_read_effect: mmu_RFID_read`, NFC starts the effect
once per cycle, waits about two seconds, then starts the next cycle. After the
last cycle it asks Happy Hare to repaint the gate map so the active test effect
stops.

On Happy Hare V3, NFC uses the public LED wrapper:

```gcode
MMU_SET_LED GATE=0 EXIT_EFFECT=mmu_RFID_read
MMU_GATE_MAP QUIET=1
```

On V4, generated `[mmu_led_effect]` instances are not accepted by that public
effect-name validator. NFC automatically uses the generated per-gate name
instead, for example `_MMU_SET_LED_EFFECT EFFECT=mmu_RFID_read_exit_0
REPLACE=1`, then stops it before returning LED control to Happy Hare. Users
still configure only the base effect name (`mmu_RFID_read`).

---

### `NFC GATE=<#> JOG_SCAN=1`

Starts the scan-and-jog sequence on demand, identical to the automatic pre-load trigger that fires when Happy Hare parks filament at the gate.

```gcode
NFC GATE=0 JOG_SCAN=1
```

**What it does:** Selects the gate, then homes the filament forward against the lane's virtual NFC endstop (`ENDSTOP=nfc_lane<N>`, see [Virtual Endstop](#virtual-endstop) below) until the tag is read or the scan limit is reached — the homing move stops the instant the tag is detected. When the tag is found it rewinds toward the parked position, leaves `scan_rewind_buffer_mm` for Happy Hare's final gate parking step, and runs `_MMU_STEP_UNLOAD_GATE`. If `scan_jog_max` is set, that distance is the scan limit; otherwise the lane's Happy Hare Bowden calibration length is used. When the limit is reached without a read, NFC follows the same rewind-and-park path and exits scan mode.

#### Virtual Endstop

Per-lane installs register each lane's NFC reader as a real Klipper/Happy Hare
gear-rail endstop via `mmu_nfc_endstop.py` (`[mmu_nfc_endstop laneN]`,
generated automatically by `install.sh` alongside each `[nfc_gate laneN]`
section — no extra hardware or config to add). It borrows the reader the
`[nfc_gate laneN]` section already owns: while Happy Hare homes against
`ENDSTOP=nfc_lane<N>`, a reactor timer polls that reader every
`poll_interval` (default `0.05s`) and reports the endstop triggered the
instant a tag UID is read. This is what lets scan-jog's forward search stop
exactly at the tag instead of jogging a fixed distance and polling
afterward. See [`[mmu_nfc_endstop laneN]`](configuration.md#mmu_nfc_endstop-lanen)
for the config keys.

Scan-jog supports two motion modes. Both home against the virtual endstop for
the forward search — the difference is whether NFC also polls the reader
while that homing move is still in flight:

| Mode | Config | Behavior |
|---|---|---|
| Continuous | `scan_motion_mode: continuous` | **Default.** Polls NFC every `scan_continuous_poll_interval` while the homing move is still in flight, recording a UID hit-window used to recenter before rich tag parsing. If a tag is found during motion, the homing move is allowed to finish before the existing 0.1 second read-light hold, rewind, and completion logic run. |
| Stopped | `scan_motion_mode: stopped` | Waits for the homing move to finish (or fail to trigger, meaning no tag was found), then reads once at that position. `scan_reads_per_position` and `scan_poll_interval` control repeat reads at that stopped position. More reliable for marginal reader or tag alignment at the cost of scan speed, since there is no in-flight UID hit-window to recenter from before a rich read. |

Default continuous scan settings:

```ini
[nfc_gate]
scan_motion_mode: continuous
scan_continuous_step_mm: 150.0
scan_continuous_speed: 200.0
scan_continuous_accel: 2000.0
scan_continuous_poll_interval: 0.05
```

The forward search homes for the full remaining scan distance in one move —
`scan_continuous_step_mm` no longer chunks that search (it's unused by the
current homing-move implementation; left in config for now). NFC polls the
reader every `0.05s` while that homing move is estimated to be in flight,
building a UID hit-window if a tag is detected before the move stops.

If a continuous UID hit occurs during motion, NFC waits for the homing move to
finish and checks Spoolman first. If the UID resolves, scan-jog finishes without
a rich read. If the UID does not resolve and rich parsing is enabled, NFC backs
up to the observed UID hit-window center before running rich tag parsing and the
normal `scan_decode_retry_mm` left/right retry sweep.

Scan-jog always clears the Happy Hare gate cache and runs the pre-scan
`MMU_SPOOLMAN SYNC=1` before moving filament. When launched from a Happy Hare
hook, those prep calls are deferred to the scan timer so the hook can return
before NFC calls back into Happy Hare.

**Happy Hare post-preload hook setup:**

The [igiannakas IG-dev branch](https://github.com/igiannakas/Happy-Hare/tree/IG-dev) of Happy Hare adds `variable_user_post_preload_extension` in `config/base/mmu_macro_vars.cfg`. Set it to drive NFC scan-jog automatically after each `MMU_PRELOAD`:

```ini
[gcode_macro _MMU_SEQUENCE_VARS]
description: Happy Hare sequence macro configuration variables
gcode: # Leave empty
variable_user_post_preload_extension: '_NFC_SCAN_JOG_PRELOAD'
```

Happy Hare appends `GATE=<n>` automatically after a successful preload. `_NFC_SCAN_JOG_PRELOAD` starts scan-jog with:

```gcode
NFC GATE=<n> JOG_SCAN=1 SOURCE=AUTO
```

NFC starts the configured scan-jog LED effect from the Python scan timer before motion begins.

`SOURCE=AUTO` identifies this as Happy Hare's own hook call. Happy Hare v4 runs
the hook while its action is often still `checking`, before it unwinds back to
`idle`, so NFC runs hook calls through the version-aware scan-safe check.

Recommended NFC config when using the hook — disables gate-status polling so HH is the sole trigger:

```ini
[nfc_gate]
startup_polling: 0
scan_enabled:    False
```

**Preconditions** (the command checks all of these and reports a plain-language error if any fail):

| Check | What it guards |
|---|---|
| Reader not in failed state | Reader must have initialised successfully |
| No active print | Scan cannot move filament during a print |
| Happy Hare scan-safe check | See below |
| No other gate currently scanning | Only one gate may hold the MMU at a time |

The scan-safe check differs by caller:

- **`SOURCE=AUTO`** (only `_NFC_SCAN_JOG_PRELOAD`, Happy Hare's own hook, sets this): Happy Hare v4 accepts `action=idle` or `action=checking`. Happy Hare v3/pre-v4 and unknown versions accept only `action=idle`.
- **Any other caller** (manual console command, macro, button; no `SOURCE=AUTO`): requires strict `action == idle`. NFC cannot verify why the command was sent, so an unlabeled call gets no benefit of the doubt.

Do not add `SOURCE=AUTO` to a manually typed `JOG_SCAN=1`; it exists only to
identify the trusted hook call, not to bypass the busy check generally.

**When to use:**
- Filament was loaded manually and the automatic trigger didn't fire (e.g. `scan_enabled: False`, or the 0→1 edge was missed)
- Retrying a scan after a failed automatic attempt
- Testing scan-jog behaviour without physically reloading filament

Expected success output:
```
NFC[lane0]: scan-jog started for gate 0 (step=50mm  max=600mm  interval=2.0s)
NFC[0] - moved 50.0mm  total 50.0mm / 600.0mm
NFC[0]: rewinding 50.0mm
```

Continuous-mode success output uses the same start/rewind messages but includes
continuous move messages while searching:

```
NFC[lane0]: continuous scan-jog started for gate 0
NFC[Lane0]: continuous Direct Move 50.0mm  scan position 50.0 / 600.0mm
NFC[Lane0]: tag found
NFC[Lane0]: rewinding 20.0mm (scan=50.0mm buffer=30.0mm)
```

If a precondition fails:
```
NFC[lane0]: Happy Hare is busy (action=loading) — wait for idle before starting scan-jog
```

---

### `NFC GATE=<#> POLL=1`

Runs one complete cycle of the NFC manager pipeline:

1. NFC reader reads the UID
2. NFC_Manager checks if the UID is new, the same, or absent
3. If new: SpoolmanClient looks up the spool ID
4. Gate state updates
5. If state changed: dispatches `_NFC_SPOOL_CHANGED`, `_NFC_SPOOL_REMOVED`, or `_NFC_TAG_NO_SPOOL`

```gcode
NFC GATE=0 POLL=1
```

**When to use:** Testing the complete pipeline end-to-end, or verifying a specific tag is registered correctly.

Expected output (registered tag):
```
NFC gate 0: spool 42 detected (UID 04AABBCCDD). Sending to Happy Hare.
```

Expected output (unregistered tag):
```
[ERROR] NFC gate 0: tag UID 04AABBCCDD is not registered in Spoolman.
Open the spool record in Spoolman, set the 'rfid_tag' extra field to: 04AABBCCDD
```

---

### `NFC GATE=<#> APPLY=1`

Forces the lane's cached spool assignment through to Happy Hare immediately. Does not read the NFC reader, does not query Spoolman — it just dispatches:

```gcode
_NFC_SPOOL_CHANGED GATE=<gate> SPOOL_ID=<cached_id> UID=<cached_uid>
```

```gcode
NFC GATE=0 APPLY=1
```

**When to use:** When a poll or polling cycle already resolved a spool, but Happy Hare didn't update (e.g. it was in a locked state during the scan). If you get "no cached spool_id", run `POLL=1` first.

---

### `NFC GATE=<#> CLEAR_CACHE=1`

Clears the lane's cached spool ID and forces a fresh Spoolman lookup on the next tag read.

```gcode
NFC GATE=0 CLEAR_CACHE=1
```

Clears:
1. The lane's cached spool ID
2. The SpoolmanClient UID cache
3. The reader driver's in-memory current-card cache

On the next poll, the full `(uid, spool_id)` combination is re-evaluated:

- **Same UID, same spool in Spoolman** → cache refreshed silently, no dispatch
- **Same UID, different spool in Spoolman** → `_NFC_SPOOL_CHANGED` dispatched with the new spool

This is the correct way to force a re-read after editing a spool's UID registration in Spoolman.

`CLEAR=1` is accepted as a shorthand.

---

### `NFC GATE=<#> HH_SYNC=1 SPOOL_ID=<n>`

Seeds this lane's cache with a spool_id from Happy Hare's gate map. On the next poll, if the physical tag resolves to that spool_id, the dispatch is suppressed (HH already knows).

```gcode
NFC GATE=0 HH_SYNC=1 SPOOL_ID=42
```

This command is normally called automatically by the `NFC_HH_SYNC_CACHE` macro — you won't need it directly in normal operation. Use `NFC_HH_SYNC_CACHE` to sync all lanes at once.

---

### `NFC GATE=<#> READ=1` / `READ=0`

Starts or stops background timer polling on one lane.

```gcode
NFC GATE=0 READ=1    ; start polling
NFC GATE=0 READ=0    ; stop polling
```

While polling is running, the lane runs `POLL=1` automatically every `poll_interval` seconds (default: 30). Macro dispatches happen automatically when gate state changes.

---

## Background Polling Setup

For production use, you want all lanes polling automatically. There are two ways to start polling:

**Manually after boot** (default — useful during setup):
```gcode
NFC GATE=0 READ=1
NFC GATE=1 READ=1
NFC GATE=2 READ=1
NFC GATE=3 READ=1
```

**Automatically on boot** (for set-and-forget operation): Add `startup_polling: 1` to each lane in `nfc_reader_hw.cfg`. The shipped hardware config staggers startup delays by 0.5 seconds so all readers don't poll at the same moment:

```ini
[nfc_gate lane0]
startup_polling:    1
startup_poll_delay: 0.0

[nfc_gate lane1]
startup_polling:    1
startup_poll_delay: 0.5

[nfc_gate lane2]
startup_polling:    1
startup_poll_delay: 1.0

[nfc_gate lane3]
startup_polling:    1
startup_poll_delay: 1.5
```

---

## Event Macros

These macros live in `nfc_macros.cfg` and are called automatically by NFC_Manager when gate state changes. You don't call these manually during normal operation, but you can call them directly to test the Happy Hare handoff without hardware.

### `_NFC_SPOOL_CHANGED`

Fires when a tag resolves to a spool and the gate state changed. Two dispatch paths depending on tag type and Spoolman availability.

**Spoolman path** — tag UID matched a Spoolman record:
```gcode
_NFC_SPOOL_CHANGED GATE=<gate> SPOOL_ID=<id> UID=<uid> [AUTO_CREATED=1] [SCAN_FINISH=1]
```

**Metadata path** — tag carries embedded filament data (Spoolman disabled or no match):
```gcode
_NFC_SPOOL_CHANGED GATE=<gate> UID=<uid> [NAME=<str>] [MATERIAL=<str>] [COLOR=<hex>] [TEMP=<int>] [SCAN_FINISH=1]
```

Parameters:
- `GATE` — Happy Hare gate number (integer, matches `mmu_gate` in config)
- `SPOOL_ID` — Spoolman spool ID (integer); present on Spoolman path only
- `UID` — NFC tag UID (hex string); always present
- `AUTO_CREATED` — `1` when `spoolman_auto_create` just created the spool record; absent otherwise
- `SCAN_FINISH` — `1` when the event came from scan-jog after rewind; accepted as a compatibility marker by the default macros
- `NAME` — display name from `material_detail` or `material`, prefixed with brand/vendor/tag format when present; metadata path only
- `MATERIAL` — filament material string from tag metadata (e.g. `PLA`, `ABS`); metadata path only
- `COLOR` — color hex string from tag metadata (e.g. `FF0000`); metadata path only
- `TEMP` — recommended extruder temperature (integer °C) from tag `min_temp` field; metadata path only

Default behavior:
```gcode
{% if params.SPOOL_ID is defined %}
    {% if auto_created %}
    MMU_SPOOLMAN REFRESH=1 QUIET=1
    {% endif %}
    MMU_GATE_MAP GATE={gate} SPOOLID={spool_id} AVAILABLE=1 SYNC=1 QUIET=1
{% else %}
    MMU_GATE_MAP GATE={gate} [NAME=..] [MATERIAL=..] [COLOR=..] [TEMP=..] AVAILABLE=1 QUIET=1
{% endif %}
MMU_GATE_MAP GATE={gate} APPLY=1 QUIET=1
```

On the Spoolman path, `AVAILABLE=1` marks the gate as loaded and `SYNC=1` lets Happy Hare push the update to Spoolman. When `AUTO_CREATED=1`, `MMU_SPOOLMAN REFRESH=1 QUIET=1` runs first so Happy Hare's Spoolman cache includes the new spool before the gate assignment is sent. On the metadata path, whatever fields are present on the tag are forwarded to `MMU_GATE_MAP`. `APPLY=1` applies the updated map immediately on both paths.

---

### `_NFC_SPOOL_REMOVED`

Fires after a previously-detected spool is absent for `absent_threshold` consecutive polls.

```gcode
_NFC_SPOOL_REMOVED GATE=<gate>
```

Parameters:
- `GATE` — Happy Hare gate number

Default behavior:
```gcode
MMU_GATE_MAP GATE={gate} SPOOLID=-1 AVAILABLE=0 SYNC=1 QUIET=1
MMU_GATE_MAP GATE={gate} APPLY=1 QUIET=1
```

Clears the gate in Happy Hare's gate map. `AVAILABLE=0` marks the gate as empty. `APPLY=1` applies the change immediately.

The macro also checks `printer.mmu.action` — if the MMU is mid-load, unload, or homing, the removal is silently ignored to avoid clearing the gate while filament is actively moving.

---

### `_NFC_TAG_NO_SPOOL`

Fires when a tag UID is detected but cannot be resolved to a spool.

```gcode
_NFC_TAG_NO_SPOOL GATE=<gate> UID=<uid> [SPOOLMAN_DISABLED=1] [SCAN_FINISH=1]
```

Parameters:
- `GATE` — Happy Hare gate number
- `UID` — the unrecognized tag UID
- `SPOOLMAN_DISABLED` — `1` when this is the no-Spoolman metadata path
- `SCAN_FINISH` — `1` when the event came from scan-jog after rewind; accepted as a compatibility marker by the default macro

Default behavior: with Spoolman enabled, prints a message with the UID and
instructions to register it. With Spoolman disabled, prints a warning that the
tag was read but no rich metadata or spool assignment was available. Both paths
clear stale visible filament fields and keep the gate loaded/available.

```gcode
MMU_GATE_MAP GATE={gate} SPOOLID=-1 NAME=Unknown MATERIAL=Unknown COLOR=FFFFFF TEMP=0 AVAILABLE=1 SYNC=1 QUIET=1
MMU_GATE_MAP GATE={gate} APPLY=1 QUIET=1
```

---

### `_NFC_SCAN_UNRESOLVED`

Fires after scan-jog rewinds when no tag/spool could be resolved. It clears stale visible Happy Hare filament metadata while keeping the gate loaded/available.

```gcode
_NFC_SCAN_UNRESOLVED GATE=<gate>
```

Default behavior:
```gcode
MMU_GATE_MAP GATE={gate} SPOOLID=-1 NAME=Unknown MATERIAL=Unknown COLOR=FFFFFF TEMP=0 AVAILABLE=1 SYNC=1 QUIET=1
MMU_GATE_MAP GATE={gate} APPLY=1 QUIET=1
```

---

## Testing the Happy Hare Handoff Without Hardware

You can test whether the macro-to-Happy-Hare pipeline works by calling the event macros directly:

```gcode
; Spoolman path
_NFC_SPOOL_CHANGED GATE=0 SPOOL_ID=42 UID=04AABBCCDD

; Metadata path
_NFC_SPOOL_CHANGED GATE=0 UID=04AABBCCDD MATERIAL=PLA COLOR=FF0000 TEMP=215

_NFC_SPOOL_REMOVED GATE=0
_NFC_TAG_NO_SPOOL GATE=0 UID=04AABBCCDD
_NFC_SCAN_UNRESOLVED GATE=0
```

If Happy Hare updates correctly, the pipeline from macro inward is working. If it doesn't, check:
- The macro body in `nfc_macros.cfg`
- Whether `MMU_GATE_MAP GATE=... SPOOLID=... AVAILABLE=1 SYNC=1 QUIET=1` is the right syntax for your Happy Hare version
- Whether Happy Hare is in a state that accepts gate map changes (e.g. not mid-print with locks active)

---
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

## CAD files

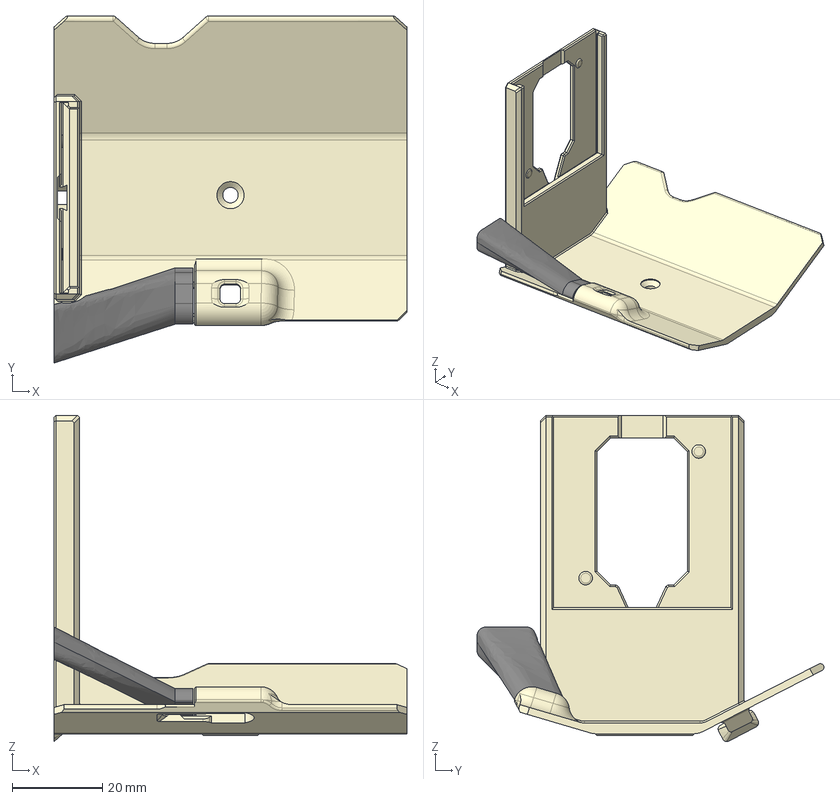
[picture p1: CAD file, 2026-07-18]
NFC Mounting Bracket/LED_holder_v3_for_EMU_PN532.step
78.0 x 76.7 x 72.2 mm

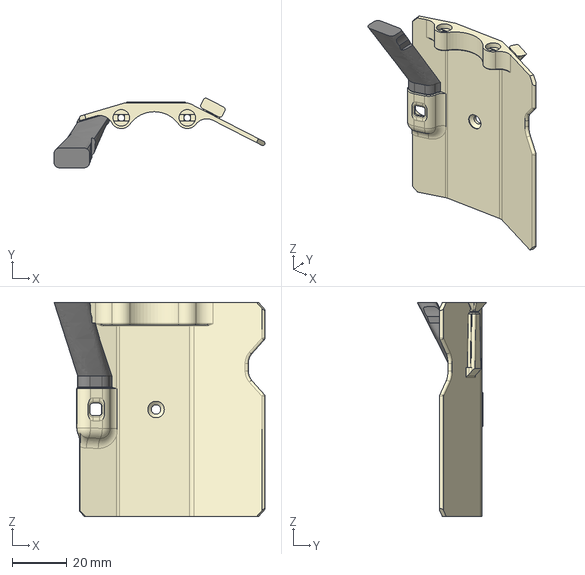
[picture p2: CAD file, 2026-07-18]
NFC Mounting Bracket/LED_holder_for_EMU_NFC_Reader_Board.step
76.7 x 25.4 x 78.0 mm

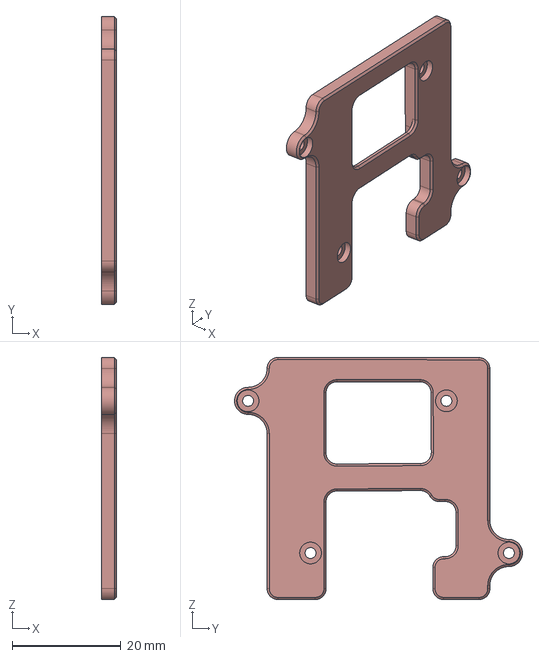
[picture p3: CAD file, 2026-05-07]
NFC Mounting Bracket/LED_holder_NFC_Guard_Bambu_height.step
2.75 x 53.0 x 44.6 mm

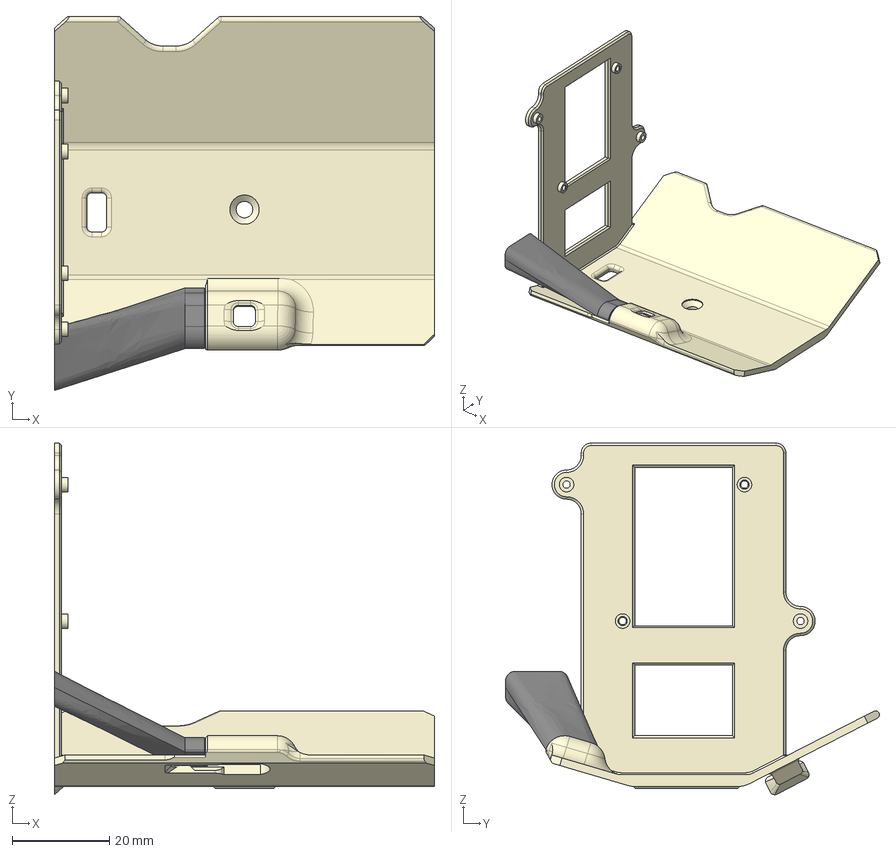
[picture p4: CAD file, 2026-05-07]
NFC Mounting Bracket/LED_holder_with_NFC_Bambu_height.step
78.0 x 76.7 x 72.2 mm

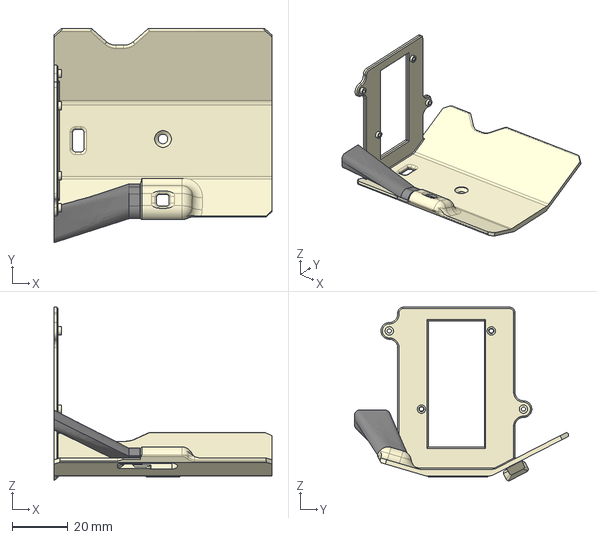
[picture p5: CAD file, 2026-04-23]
NFC Mounting Bracket/LED_holder_No_cover_with_NFC.step
78.0 x 76.7 x 62.2 mm

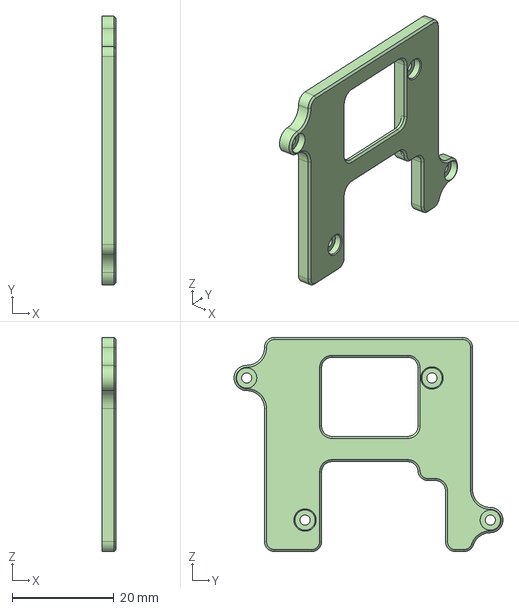
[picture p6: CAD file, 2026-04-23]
NFC Mounting Bracket/LED_holder_NFC_Guard.step
2.75 x 53.0 x 42.2 mm

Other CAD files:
NFC Mounting Bracket/LED_holder_NFC_Guard.stl
NFC Mounting Bracket/LED_holder_NFC_Guard_Bambu_height.stl
NFC Mounting Bracket/LED_holder_No_cover_with_NFC.stl
NFC Mounting Bracket/LED_holder_for_EMU_NFC_Reader_Board.stl
NFC Mounting Bracket/LED_holder_v3_for_EMU_PN532.stl
NFC Mounting Bracket/LED_holder_with_NFC_Bambu_height.stl

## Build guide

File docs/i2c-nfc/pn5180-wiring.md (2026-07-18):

# Wiring the PN5180

[NFC Reader Wiring](wiring.md) | [Configuration](../shared/configuration.md) | [Setup](setup.md)

PN5180 is an SPI NFC controller. In this project it supports ISO14443A tags
(including NTAG and authenticated MIFARE/Bambu reads) and SLIX2
(ISO15693/Type-5) tags.
It can be configured as a shared reader or as a per-lane reader with
`reader_type: pn5180`.

SLIX2 support is not limited to OpenPrintTag. After the Type-5 user memory is
read, the reader path removes the Type-5 Capability Container when present and
passes the remaining bytes to the normal tag parser. The payload is therefore
handled according to its actual supported format, not a reader-specific format.

This page uses the Happy Hare SLB/MMU board as a concrete wiring example. Pin
names and power connectors vary on other boards; use their equivalent MCU GPIO
and power connections instead.

## Required Connections

The PN5180 setup requires all nine connections below. `BUSY` and `RST` are not
optional: the driver waits for the active-high BUSY signal around every command
and uses RST to recover a reader that has stopped responding.

| PN5180 module pin | SLB/MMU connection | Config setting | Required purpose |
|---|---|---|---|
| `SCK` | `PB13` | `spi_bus: spi2_PB14_PB15_PB13` | SPI clock |
| `MISO` | `PB14` | `spi_bus: spi2_PB14_PB15_PB13` | SPI data from reader |
| `MOSI` | `PB15` | `spi_bus: spi2_PB14_PB15_PB13` | SPI data to reader |
| `NSS` / `CS` | `PA8` | `cs_pin: mmu:PA8` | SPI chip select |
| `BUSY` | `PB0` | `busy_pin: mmu:PB0` | Active-high command-complete signal |
| `RST` | `PC6` | `reset_pin: mmu:PC6` | MCU-controlled hardware reset |
| `5V` | SLB/MMU 5V supply | - | RF/front-end power |
| `3.3V` | **PSF connector 3.3V** | - | Logic/SPI power; must be connected |
| `GND` | SLB/MMU GND | - | Common ground |

> [!IMPORTANT]
> The PN5180 breakout used for this wiring needs both `5V` and `3.3V`. Do not
> omit the 3.3V wire or replace it with 5V. Connect its 3.3V pin to the PSF
> connector's 3.3V supply, and ensure every signal shares the same ground.

The module's `IRQ`, `GPIO`, and `AUX` pins are not used by the current driver.
It polls the PN5180 internal IRQ status through SPI, so leave those pins
unconnected unless another circuit requires them.

## SPI Speed

Both PN5180 and RC522 default to `spi_speed: 500000` with hardware SPI. This is
a conservative starting point for MMU wiring. Software SPI can also be used
when the MCU has no suitable hardware bus, but set `spi_speed: 100000` because
bit-banged SPI is less tolerant of high rates.

## Shared Reader Configuration

Put this in `[nfc_gate shared]` in `nfc_reader_shared.cfg` for the SLB wiring
above. Keep the existing `i2c_mcu: mmu` line in the section; it identifies the
reader's Klipper MCU even though the PN5180 itself uses SPI.

```ini
[nfc_gate shared]
enabled:                True
reader_type:            pn5180
i2c_mcu:                mmu
spi_bus:                spi2_PB14_PB15_PB13
cs_pin:                 mmu:PA8
reset_pin:              mmu:PC6
busy_pin:               mmu:PB0
spi_speed:              500000
shared:                 true
startup_polling:        1
```

`reset_pin` has no implicit fallback and must be present in the configuration.
`busy_pin` defaults to `mmu:PB0`, but explicitly setting it is recommended so
the configured wire is clear. The BUSY wire itself is mandatory in either case.

## Per-Lane Configuration

Use the same reader-specific settings in the matching lane section. Replace the
MCU prefix and SPI bus with the actual lane MCU wiring.

```ini
[nfc_gate lane0]
enabled:                True
reader_type:            pn5180
mmu_gate:               0
i2c_mcu:                mmu
spi_bus:                spi2_PB14_PB15_PB13
cs_pin:                 mmu:PA8
reset_pin:              mmu:PC6
busy_pin:               mmu:PB0
spi_speed:              500000
```

For software SPI, replace `spi_bus` with Klipper's
`spi_software_sclk_pin`, `spi_software_mosi_pin`, and
`spi_software_miso_pin` settings, retain `cs_pin`, `busy_pin`, and `reset_pin`,
and set `spi_speed: 100000`.

## Bring-Up Checks

1. Confirm all nine connections, especially both power rails and the common
   ground.
2. Confirm `BUSY` reaches the configured GPIO and is not inverted. It is
   active high.
3. Confirm `RST` reaches the configured GPIO; do not tie RST permanently high.
4. Confirm the selected SPI bus matches `PB13`/`PB14`/`PB15` on the SLB.
5. Restart Klipper and run `NFC_SHARED INIT=1` or `NFC GATE=<n> INIT=1`.
6. Run `NFC_SHARED SCAN=1` or `NFC GATE=<n> SCAN=1` with a tag nearby.

If the reader reports a BUSY timeout or invalid health registers, first check
the 3.3V wire, BUSY, RST, MISO, chip select, and common ground. A working reset
wire lets the driver recover from a communication lockup without unplugging the
module.

---

*Copyright (C) 2026 WoodWorker. Licensed under [GPL-3.0-or-later](https://www.gnu.org/licenses/gpl-3.0.html) - see [LICENSE](../../LICENSE).*

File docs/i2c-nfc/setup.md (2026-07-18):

# First-Time Setup

[← Install](../shared/install-uninstall.md) | [Spoolman Setup →](../shared/spoolman-integration.md)

This guide assumes you have:
- [Wired the NFC reader](wiring.md)
- [Installed the software](../shared/install-uninstall.md)
- Rebuilt and flashed Klipper firmware on every lane MCU

If you skipped any of those, do them first.

---

## Step 1 — Add Includes to `printer.cfg`

Add these three lines in this exact order:

```ini
[include nfc/nfc_reader.cfg]
[include nfc/nfc_macros.cfg]
[include nfc/nfc_reader_hw.cfg]
```

`nfc_reader.cfg` must come first — it defines the base `[nfc_gate]` section that each `[nfc_gate laneN]` in `nfc_reader_hw.cfg` inherits from. Reversing the order causes a Klipper config error on startup.

---

## Step 2 — Configure Spoolman

Edit `~/printer_data/config/nfc/nfc_reader.cfg`:

```ini
[nfc_gate]
spoolman_url:      auto
spoolman_rfid_key: rfid_tag
```

| Setting | Value | When to use |
|---|---|---|
| `spoolman_url: auto` | Reads URL from Moonraker | Use this when `moonraker.conf` has a `[spoolman]` section |
| `spoolman_url: http://host:7912` | Direct URL | Use when testing, or if `auto` isn't working |
| `spoolman_rfid_key: rfid_tag` | Extra field name | Must match what you create in Spoolman Settings |

See [Spoolman Integration](../shared/spoolman-integration.md) — you need to create the extra field in Spoolman and register each tag UID before spool detection will work.

---

## Step 3 — Configure Lane Hardware

Edit `~/printer_data/config/nfc/nfc_reader_hw.cfg`. The default file has four lanes; adjust to match your printer:

```ini
[nfc_gate lane0]
enabled:    True
mmu_gate:   0
i2c_mcu:    mmu0

[nfc_gate lane1]
enabled:    True
mmu_gate:   1
i2c_mcu:    mmu1
```

| Key | Required | Value |
|---|:---:|---|
| `mmu_gate` | Yes | Happy Hare gate number (0-based integer) |
| `i2c_mcu` | Yes | Klipper MCU name — must match an `[mcu laneN]` in your config |
| `enabled` | No | Defaults to `True`. Set `False` to keep a future lane template without creating hardware. |
| `reader_type` | Inherited unless overridden | `pn532` by default. Set `pn7160`, `rc522`, or `pn5180` for the installed reader. |
| `i2c_address` | Inherited unless overridden | PN532 uses `36`; PN7160 must use `40-43`. Not used by RC522 or PN5180. |
| `i2c_bus` | Inherited unless overridden | I2C bus name on that MCU — use `i2c3_PB3_PB4` for PB3/PB4 on EBB42 or set it once in `[nfc_gate]`. Not used by RC522 or PN5180. |

| `spi_bus`, `cs_pin`, `spi_speed` | SPI readers | Required for RC522 and PN5180. Use `500000` for hardware SPI or `100000` for software SPI. |
| `reset_pin`, `busy_pin` | PN5180 | Required PN5180 RST and active-high BUSY GPIO. See [PN5180 wiring](pn5180-wiring.md). |

> [!NOTE]
> `i2c_mcu` must exactly match the MCU name Klipper uses. These names come from Happy Hare's `mmu_hardware.cfg`, typically `lane0`, `lane1`, etc. A mismatch causes a Klipper startup error.

> [!IMPORTANT]
> **Temperature sensor I2C bus must match.** If your lane MCU has a thermistor or temperature sensor on I2C (e.g. an SHT3x), configure it on the **same I2C bus** as the NFC reader. PN532 should use hardware I2C. PN7160 supports software I2C, but hardware I2C is recommended because software I2C increases MCU load.

PN7160 lane example:

```ini
[nfc_gate lane1]
enabled:     True
reader_type: pn7160
i2c_address: 40
mmu_gate:    1
i2c_mcu:     mmu1
```

All polling, timing, and logging settings are inherited from the base `[nfc_gate]` in `nfc_reader.cfg`. Override per-lane only if you need different behavior on a specific lane:

```ini
[nfc_gate lane2]
enabled:    True
mmu_gate:   2
i2c_mcu:    mmu2
debug:      2              ; verbose logging on this lane only
```

---

## Step 4 — Restart Klipper

```bash
sudo systemctl restart klipper
```

Watch the log for NFC startup messages:

```bash
tail -f ~/printer_data/logs/nfc_reader.log
```

Errors at this stage are almost always config typos or a missing/mismatched lane MCU name.

---

## Step 5 — Verify Each Reader

### 1. Check all gates

```gcode
NFC_STATUS
```

Expected with no tags loaded:
```
NFC gate status  (4 gates configured):
  Gate 0  [lane0]:  empty
  Gate 1  [lane1]:  empty
  Gate 2  [lane2]:  empty
  Gate 3  [lane3]:  empty
```

### 2. Watch the startup console output

When Klipper connects, each lane initialises automatically and reports to the console. Look for:

```
[OK] NFC[lane0]: ready.  HH seed: spool_id=42  Startup polling is enabled; first poll in 0.0s.
```

or, if the gate was empty in Happy Hare:

```
[OK] NFC[lane0]: ready.  HH reports gate empty  Run NFC GATE=0 READ=1 to start polling.
```

**The HH seed line is important.** It means NFC_Manager read Happy Hare's gate map on startup and pre-loaded the lane cache with the spool HH already knows about. The first poll will verify the physical tag matches that spool — if it does, no redundant dispatch is sent to Happy Hare. If the spool was swapped while Klipper was down, the mismatch is detected and `_NFC_SPOOL_CHANGED` fires normally.

If Happy Hare wasn't ready when the NFC init ran, the seed step is skipped. Run `NFC_HH_SYNC_CACHE` to manually re-seed all lanes from the current HH gate map.

### 3. Initialize a lane manually

```gcode
NFC GATE=0 INIT=1
```

This runs the configured NFC reader initialization. Expected output:
```
[OK] NFC[lane0]: reader OK
```

If it fails, check [Troubleshooting](troubleshooting.md).

### 4. Hardware scan

Hold an NFC tag near the reader, then:

```gcode
NFC GATE=0 SCAN=1
```

The UID prints to the console. This is a raw hardware read — no Spoolman lookup, no Happy Hare update.

### 5. Full pipeline test

With a registered tag (see [Spoolman Integration](../shared/spoolman-integration.md)):

```gcode
NFC GATE=0 POLL=1
```

Expected result:
```
NFC[lane0]: one poll complete; Gate 0:  spool 42  UID 04AABBCCDD ...
```

This runs the full chain: NFC reader read → Spoolman lookup → state update → Happy Hare macro. If this works, the pipeline is complete.

---

## Step 6 — Enable Background Polling

Once a lane works end-to-end, start automatic polling:

```gcode
NFC GATE=0 READ=1
```

To start all lanes, run `READ=1` for each. Polling runs at the `poll_interval` (default: 10 seconds).

**Optional: automatic polling on startup.**
To have lanes start polling automatically after Klipper boots, set `startup_polling: 1`. The shipped `nfc_reader_hw.cfg` staggers the per-lane startup delays by 0.5 seconds so all readers don't poll simultaneously:

```ini
[nfc_gate lane0]
startup_polling:    1
startup_poll_delay: 0.0

[nfc_gate lane1]
startup_polling:    1
startup_poll_delay: 0.5

[nfc_gate lane2]
startup_polling:    1
startup_poll_delay: 1.0

[nfc_gate lane3]
startup_polling:    1
startup_poll_delay: 1.5
```

---

## Next Steps

- [Spoolman Integration](../shared/spoolman-integration.md) — register your tag UIDs
- [Commands & Macros](../shared/klipper-functions.md) — full command reference
- [Configuration Reference](../shared/configuration.md) — tune polling, logging, and timing

---

*Copyright (C) 2026 WoodWorker. Licensed under [GPL-3.0-or-later](https://www.gnu.org/licenses/gpl-3.0.html) — see [LICENSE](../../LICENSE).*

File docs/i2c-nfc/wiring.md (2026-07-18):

# NFC Reader Wiring

[README](../../Readme.md) | [Next: Install](../shared/install-uninstall.md)

This project supports PN532 and PN7160 over I2C, plus RC522 and PN5180 over
SPI. RC522 and PN5180 do not use the I2C wiring or address settings below.

| Reader | `reader_type` | Address | Bus | Best use |
|---|---|---|---|---|
| PN532 | `pn532` | `36` (`0x24`) fixed | Hardware I2C | Default, simple UID/NTAG/Bambu reader path |
| PN7160 | `pn7160` | `40-43` (`0x28-0x2B`) selectable | Hardware I2C recommended; software I2C supported | Type5/ISO15693, OpenPrintTag SLIX2, PN7160 hardware |
| RC522 | `rc522` | - | SPI | UID lookup, NTAG/Type-2, and MIFARE/Bambu reads |
| PN5180 | `pn5180` | - | SPI | ISO14443A/MIFARE and SLIX2 (ISO15693/Type-5) reads |

Use the reader-specific wiring page for the electrical details:

- [PN532 wiring](pn532-wiring.md)
- [PN7160 wiring](pn7160-wiring.md)
- [PN5180 wiring](pn5180-wiring.md) - SLB nine-wire example, power, BUSY, and RST

## Per-Lane Readers

For per-lane EMU readers, each filament gate normally gets one NFC reader wired
to that lane MCU / EBB42. Each lane has its own I2C bus, so readers on different
lane MCUs may reuse the same I2C address.

```text
lane0 EBB42  -> I2C -> NFC reader (gate 0)
lane1 EBB42  -> I2C -> NFC reader (gate 1)
lane2 EBB42  -> I2C -> NFC reader (gate 2)
```

## Shared Reader

The optional shared reader is a single NFC reader mounted inside the MMU body
and configured in `nfc_reader_shared.cfg`. It can be PN532, PN7160, RC522, or
PN5180. I2C readers need suitable SDA/SCL pins; SPI readers need a suitable
SPI bus plus chip select. The reader MCU can be the MMU MCU, a toolhead MCU, or
another MCU declared with an `[mcu ...]` section.

See [Shared Reader](../shared/shared-reader.md) for the workflow and config.

## Bus Choice

PN532 should use hardware I2C.

PN7160 supports Klipper software I2C, but hardware I2C is recommended. Software
I2C bit-bangs SDA/SCL in MCU firmware, which increases MCU load. Use software
I2C only when the selected MCU has no suitable hardware I2C bus and after bench
testing the reader.

RC522 and PN5180 use Klipper SPI. Start at `spi_speed: 500000` with a hardware
SPI bus. When software SPI is required, explicitly set `spi_speed: 100000`.
PN5180 also requires the dedicated BUSY and RST GPIO connections described in
the [PN5180 wiring guide](pn5180-wiring.md).

## Common Bring-Up Order

1. Confirm the MCU connects normally before adding the reader.
2. Wire VCC and GND.
3. Wire SDA and SCL.
4. Set the correct `reader_type` and `i2c_address`.
5. Restart Klipper.
6. Run `NFC GATE=0 INIT=1` or `NFC_SHARED INIT=1`.
7. Run `NFC GATE=0 SCAN=1` or `NFC_SHARED SCAN=1` with a tag nearby.

If basic init fails, use the reader-specific troubleshooting checks first.

---

*Copyright (C) 2026 WoodWorker. Licensed under [GPL-3.0-or-later](https://www.gnu.org/licenses/gpl-3.0.html) - see [LICENSE](../../LICENSE).*

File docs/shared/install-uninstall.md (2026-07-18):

# Install & Uninstall

[← README](../../Readme.md) | [Wiring](../i2c-nfc/wiring.md) | [Setup →](../i2c-nfc/setup.md)

---

## How the Install Works

The installer creates **symlinks** — it does not copy Python files into the Klipper directory. This means:

- Updating is just `git pull` — the new code is live immediately, no file copy needed
- Config files in `~/printer_data/config/nfc/` are yours — the installer never overwrites sections you have already edited
- Running `bash install.sh` again after an update is always safe

**What gets created:**

```
~/klipper/klippy/extras/nfc_gate.py         →  symlink → repo/klippy/extras/nfc_gate.py
~/klipper/klippy/extras/nfc_gates/          →  symlink → repo/klippy/extras/nfc_gates/
~/klipper/klippy/extras/mmu_nfc_endstop.py  →  symlink → repo/klippy/extras/mmu_nfc_endstop.py
~/printer_data/config/nfc/nfc_reader.cfg
~/printer_data/config/nfc/nfc_macros.cfg
~/printer_data/config/nfc/nfc_reader_hw.cfg
~/printer_data/config/nfc/nfc_reader_shared.cfg
```

`mmu_nfc_endstop.py` registers each enabled lane's NFC reader as a Happy Hare
gear-rail homing endstop. `nfc_reader_hw.cfg` gets one `[mmu_nfc_endstop
laneN]` section per enabled lane automatically, alongside the matching
`[nfc_gate laneN]` — see [Virtual Endstop](../shared/klipper-functions.md#virtual-endstop).

Config files use a non-destructive merge: if a section already exists in your file, it is left alone. Only missing sections are appended.

---

## Install

### Step 1 — Flash Lane MCU Firmware

> [!CAUTION]
> Do this before anything else. The NFC reader driver communicates directly with the MCU firmware over I2C. If the host Klipper and the MCU firmware are on different versions, I2C reads fail with errors that look like hardware faults.
>
> Build and flash Klipper firmware for every MCU that will carry an NFC reader before you run the installer.

### Step 2 — Clone the Repository

SSH to the Pi:

```bash
cd ~
git clone https://github.com/cwiegert/Happy-Hare-RFID-Reader.git rfid-reader
cd ~/rfid-reader
```

The installer configures a sparse checkout automatically — documentation and other non-runtime files are excluded from the Pi.

> [!IMPORTANT]
> Beta cutover: old `~/emu-nfc-reader` installs are not migrated in place. Clone this repo into `~/rfid-reader` and run `bash install.sh`. If the installer finds `~/emu-nfc-reader`, it prompts before backing up `~/printer_data/config/nfc/`, backing up `moonraker.conf`, removing the old Moonraker update-manager block, removing the old clone, and continuing with a fresh install.

### Step 3 — Run the Installer

```bash
bash install.sh
```

The installer prints what it creates. If it cannot find the Klipper extras directory or the printer config directory, it exits with an error before making any changes.

For per-lane readers, the installer asks for the Happy Hare version. Select
`v3` for the conventional `lane0` / `mmu0` layout. Select `v4` for Happy Hare
V4's default single-unit layout; it creates matching `unit0_laneN`,
`unit0_gateN`, and `nfc_unit0_laneN` sections. The V4 option deliberately
uses only the standard `unit0` layout. Multi-unit or custom gate mappings must
be edited in `nfc_reader_hw.cfg` after installation.

### Step 4 — Add Includes to `printer.cfg`

Open `~/printer_data/config/printer.cfg` and add the matching includes in this order.

Per-lane readers:

```ini
[include nfc/nfc_reader.cfg]
[include nfc/nfc_macros.cfg]
[include nfc/nfc_reader_hw.cfg]
```

Shared-reader-only:

```ini
[include nfc/nfc_reader.cfg]
[include nfc/nfc_macros.cfg]
[include nfc/nfc_reader_shared.cfg]
```

Hybrid:

```ini
[include nfc/nfc_reader.cfg]
[include nfc/nfc_macros.cfg]
[include nfc/nfc_reader_hw.cfg]
[include nfc/nfc_reader_shared.cfg]
```

Order is required. `nfc_reader.cfg` defines the base `[nfc_gate]` section that each lane section inherits from. Including the lane file first causes a Klipper startup error.

### Step 5 — Configure Spoolman

Edit `~/printer_data/config/nfc/nfc_reader.cfg`:

```ini
[nfc_gate]
spoolman_url:      auto
spoolman_rfid_key: rfid_tag
```

**`spoolman_url: auto`** works when Moonraker has a `[spoolman]` section configured. Use a direct URL if you need to point at a specific instance:

```ini
spoolman_url: http://192.168.1.50:7912
```

See [Spoolman Integration](spoolman-integration.md) for how to create the extra field and register UIDs.

### Step 6 — Configure Lane Hardware

Edit `~/printer_data/config/nfc/nfc_reader_hw.cfg`. The default file has four lanes — adjust the MCU names and gate numbers to match your Happy Hare setup:

```ini
[nfc_gate lane0]
enabled: True
mmu_gate: 0
i2c_mcu:  mmu0
```

`i2c_mcu` must exactly match the MCU name in your Happy Hare config (from `mmu_hardware.cfg`), typically `mmu0`, `mmu1`, etc. `i2c_bus` can be set once in the base `[nfc_gate]` section or overridden per lane. RC522 and PN5180 use SPI settings instead; PN5180 additionally requires wired `reset_pin` and active-high `busy_pin`. See [PN5180 wiring](../i2c-nfc/pn5180-wiring.md) for the SLB nine-wire example.

> [!IMPORTANT]
> **Temperature sensor I2C bus must match.** If your lane MCU also has a thermistor or temperature sensor connected over I2C (e.g. an SHT3x), configure it on the same I2C bus as the NFC reader. PN532 should use hardware I2C. PN7160 supports software I2C, but hardware I2C is recommended because software I2C increases MCU load.

See [Configuration Reference](configuration.md) for all available settings.

### Step 7 — Restart and Verify

```bash
sudo systemctl restart klipper
```

```gcode
NFC_STATUS
NFC_DOCTOR
```

Expected output with no tags loaded:

```
NFC gate status  (4 gates configured):
  Gate 0  [lane0]:  empty
  Gate 1  [lane1]:  empty
  Gate 2  [lane2]:  empty
  Gate 3  [lane3]:  empty
```

If you see errors, check [Troubleshooting](../i2c-nfc/troubleshooting.md).

---

### Per-Lane Readers — Required Hook

Wire the Happy Hare post-preload hook so scan-jog triggers automatically after each preload. This requires the [igiannakas IG-dev branch](https://github.com/igiannakas/Happy-Hare/tree/IG-dev) of Happy Hare, which adds `variable_user_post_preload_extension` to `mmu_macro_vars.cfg`.

**Wire the scan-jog hook.** Open `~/printer_data/config/mmu/base/mmu_macro_vars.cfg` and add:

```ini
[gcode_macro _MMU_SEQUENCE_VARS]
variable_user_post_preload_extension: '_NFC_SCAN_JOG_PRELOAD'
```

Happy Hare appends `GATE=<n>` automatically. `_NFC_SCAN_JOG_PRELOAD` calls `NFC GATE=<n> JOG_SCAN=1 SOURCE=AUTO`; NFC starts the configured scan-jog LED effect from the Python scan timer before motion begins. With this wired, set `scan_enabled: False` so Happy Hare is the sole scan-jog trigger:

```ini
[nfc_gate]
scan_enabled: False
```

`SOURCE=AUTO` identifies this as Happy Hare's own hook call. Happy Hare v4 can
run the hook while its action is still `checking`, before it unwinds back to
`idle`, so NFC runs hook calls through the version-aware scan-safe check.
Manual or console `JOG_SCAN=1` commands without `SOURCE=AUTO` still require
strict `action=idle`.

Without this hook wired, scan-jog falls back to triggering on gate status change (`scan_enabled: True`), which is less reliable than the preload hook.

---

### Shared Reader — Additional Required Steps

If you are using the shared reader (`[nfc_gate shared]`), two more things must be configured before it will work. Both require the [igiannakas IG-dev branch](https://github.com/igiannakas/Happy-Hare/tree/IG-dev) of Happy Hare, which adds `variable_user_post_preload_extension` to `mmu_macro_vars.cfg`.

**Wire the Happy Hare preload hook.** Open `~/printer_data/config/mmu/base/mmu_macro_vars.cfg` and add:

```ini
[gcode_macro _MMU_SEQUENCE_VARS]
variable_user_post_preload_extension: '_NFC_SHARED_PRELOAD'
```

Without this, NFC never sees the preload event and the spool ID is never applied to the gate.

If this value is still set to `NFC JOG_SCAN=1`, the printer is using the per-lane reader hook. Shared-reader loads will stage a spool, but the post-preload commit will not run; the pending spool will eventually time out and you may see `NFC GATE=<n>` errors.

**Set the pending timeout.** Open `~/printer_data/config/mmu/base/mmu_parameters.cfg` and set:

```ini
pending_spool_id_timeout: 120   # seconds between tapping the tag and inserting filament
```

NFC reads this value automatically at connect time (falls back to 30 s if not set). 30 s is short enough that a first load will almost always time out before the filament reaches the gate — increase it to match your typical tap-to-load time.

---

## Moonraker Update Manager

The installer adds this block to `~/printer_data/config/moonraker.conf` automatically. If it was not found or you need to add it manually:

```ini
[update_manager Happy-Hare-RFID-Reader]
type:             git_repo
path:             ~/rfid-reader
origin:           https://github.com/cwiegert/Happy-Hare-RFID-Reader.git
primary_branch:   main
managed_services: klipper
install_script:   install.sh
```

Restart Moonraker:

```bash
sudo systemctl restart moonraker
```

> [!NOTE]
> The update manager runs `install.sh` automatically after pulling. Since the Python extras are symlinks, new code is live immediately after the pull. You still need to **manually rebuild and flash lane MCU firmware** when a Klipper MCU protocol change is included in an update — the update notes will say so.

---

## Updating

```bash
cd ~/rfid-reader
git pull
bash install.sh
sudo systemctl restart klipper
```

If the update notes mention a Klipper MCU protocol change, rebuild and flash each lane MCU before restarting Klipper.

---

## Uninstall

```bash
cd ~/rfid-reader
bash uninstall.sh
```

The uninstaller:

1. Removes the `nfc_gate.py` symlink from Klipper extras
2. Removes the `nfc_gates/` symlink from Klipper extras
3. Removes legacy `~/pn532_scan.py` if an older installer placed it there
4. Removes the `mmu_nfc_endstop.py` symlink from Klipper extras
5. Moves `~/printer_data/config/nfc/` to `nfc_removed_<timestamp>/` (your config is preserved, not deleted)
6. Restarts Klipper

At the end, it prompts whether to remove the local repo checkout at
`~/rfid-reader`. The default answer is yes. Answer `n` to keep the checkout.

**Manual steps after uninstalling** — the uninstaller cannot edit your config files:

Remove these three lines from `printer.cfg`:
```ini
[include nfc/nfc_reader.cfg]
[include nfc/nfc_macros.cfg]
[include nfc/nfc_reader_hw.cfg]
```

Remove the update manager block from `moonraker.conf`, then restart Moonraker:

```ini
[update_manager Happy-Hare-RFID-Reader]
```

If you are cleaning up an earlier beta, also remove either old block if present:

```ini
[update_manager emu_nfc_reader]
[update_manager happy_hare_rfid_reader]
[update_manager Happy-Hare-rfid-reader]
```

```bash
sudo systemctl restart moonraker
```

Delete the config backup when you no longer need it:
```bash
rm -rf ~/printer_data/config/nfc_removed_*
```

---

*Copyright (C) 2026 WoodWorker. Licensed under [GPL-3.0-or-later](https://www.gnu.org/licenses/gpl-3.0.html) — see [LICENSE](../../LICENSE).*

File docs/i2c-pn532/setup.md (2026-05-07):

# First-Time Setup

[← Install](../shared/install-uninstall.md) | [Spoolman Setup →](../shared/spoolman-integration.md)

This guide assumes you have:
- [Wired the PN532](wiring.md) readers and set them to I2C mode
- [Installed the software](../shared/install-uninstall.md)
- Rebuilt and flashed Klipper firmware on every lane MCU

If you skipped any of those, do them first.

---

## Step 1 — Add Includes to `printer.cfg`

Add these three lines in this exact order:

```ini
[include nfc/nfc_reader.cfg]
[include nfc/nfc_macros.cfg]
[include nfc/nfc_reader_hw.cfg]
```

`nfc_reader.cfg` must come first — it defines the base `[nfc_gate]` section that each `[nfc_gate laneN]` in `nfc_reader_hw.cfg` inherits from. Reversing the order causes a Klipper config error on startup.

---

## Step 2 — Configure Spoolman

Edit `~/printer_data/config/nfc/nfc_reader.cfg`:

```ini
[nfc_gate]
spoolman_url:      auto
spoolman_rfid_key: rfid_tag
```

| Setting | Value | When to use |
|---|---|---|
| `spoolman_url: auto` | Reads URL from Moonraker | Use this when `moonraker.conf` has a `[spoolman]` section |
| `spoolman_url: http://host:7912` | Direct URL | Use when testing, or if `auto` isn't working |
| `spoolman_rfid_key: rfid_tag` | Extra field name | Must match what you create in Spoolman Settings |

See [Spoolman Integration](../shared/spoolman-integration.md) — you need to create the extra field in Spoolman and register each tag UID before spool detection will work.

---

## Step 3 — Configure Lane Hardware

Edit `~/printer_data/config/nfc/nfc_reader_hw.cfg`. The default file has four lanes; adjust to match your printer:

```ini
[nfc_gate lane0]
mmu_gate:   0
i2c_mcu:    mmu0
i2c_bus:    i2c3_PB3_PB4

[nfc_gate lane1]
mmu_gate:   1
i2c_mcu:    mmu1
i2c_bus:    i2c3_PB3_PB4
```

| Key | Required | Value |
|---|:---:|---|
| `mmu_gate` | Yes | Happy Hare gate number (0-based integer) |
| `i2c_mcu` | Yes | Klipper MCU name — must match an `[mcu laneN]` in your config |
| `i2c_bus` | Yes | I2C bus name on that MCU — use `i2c3_PB3_PB4` for PB3/PB4 on EBB42 |

> [!NOTE]
> `i2c_mcu` must exactly match the MCU name Klipper uses. These names come from Happy Hare's `mmu_hardware.cfg`, typically `lane0`, `lane1`, etc. A mismatch causes a Klipper startup error.

> [!IMPORTANT]
> **Temperature sensor I2C bus must match.** If your lane MCU has a thermistor or temperature sensor on I2C (e.g. an SHT3x), configure it on the **same hardware I2C bus** as the PN532 — the same `i2c_bus` value used in `[nfc_gate laneN]` or the base `[nfc_gate]`. Klipper's software-emulated I2C (`i2c_software_*`) is not compatible with the PN532 driver; hardware I2C is required for both devices.

All polling, timing, and logging settings are inherited from the base `[nfc_gate]` in `nfc_reader.cfg`. Override per-lane only if you need different behavior on a specific lane:

```ini
[nfc_gate lane2]
mmu_gate:   2
i2c_mcu:    mmu2
i2c_bus:    i2c3_PB3_PB4
debug:      2              ; verbose logging on this lane only
```

---

## Step 4 — Restart Klipper

```bash
sudo systemctl restart klipper
```

Watch the log for NFC startup messages:

```bash
tail -f ~/printer_data/logs/nfc_reader.log
```

Errors at this stage are almost always config typos or a missing/mismatched lane MCU name.

---

## Step 5 — Verify Each Reader

### 1. Check all gates

```gcode
NFC_STATUS
```

Expected with no tags loaded:
```
NFC gate status  (4 gates configured):
  Gate 0  [lane0]:  empty
  Gate 1  [lane1]:  empty
  Gate 2  [lane2]:  empty
  Gate 3  [lane3]:  empty
```

### 2. Watch the startup console output

When Klipper connects, each lane initialises automatically and reports to the console. Look for:

```
✅ NFC[lane0]: reader ready.  HH seed: spool_id=42  Startup polling is enabled; first poll in 0.0s.
```

or, if the gate was empty in Happy Hare:

```
✅ NFC[lane0]: reader ready.  HH reports gate empty  Run NFC GATE=0 READ=1 to start polling.
```

**The HH seed line is important.** It means NFC_Manager read Happy Hare's gate map on startup and pre-loaded the lane cache with the spool HH already knows about. The first poll will verify the physical tag matches that spool — if it does, no redundant dispatch is sent to Happy Hare. If the spool was swapped while Klipper was down, the mismatch is detected and `_NFC_SPOOL_CHANGED` fires normally.

If Happy Hare wasn't ready when the NFC init ran, the seed step is skipped. Run `NFC_HH_SYNC_CACHE` to manually re-seed all lanes from the current HH gate map.

### 3. Initialize a lane manually

```gcode
NFC GATE=0 INIT=1
```

This runs the PN532 `GetFirmwareVersion` and `SAMConfiguration` handshake. Expected output:
```
NFC[lane0]: reader OK
```

If it fails, check [Troubleshooting](troubleshooting.md).

### 4. Hardware scan

Hold an NFC tag near the reader, then:

```gcode
NFC GATE=0 SCAN=1
```

The UID prints to the console. This is a raw hardware read — no Spoolman lookup, no Happy Hare update.

### 5. Full pipeline test

With a registered tag (see [Spoolman Integration](../shared/spoolman-integration.md)):

```gcode
NFC GATE=0 POLL=1
```

Expected console output:
```
NFC gate 0: spool 42 detected (UID 04AABBCCDD). Sending to Happy Hare.
```

This runs the full chain: PN532 read → Spoolman lookup → state update → Happy Hare macro. If this works, the pipeline is complete.

---

## Step 6 — Enable Background Polling

Once a lane works end-to-end, start automatic polling:

```gcode
NFC GATE=0 READ=1
```

To start all lanes, run `READ=1` for each. Polling runs at the `poll_interval` (default: 30 seconds).

**Optional: automatic polling on startup.**
To have lanes start polling automatically after Klipper boots, set `startup_polling: 1`. The shipped `nfc_reader_hw.cfg` staggers the per-lane startup delays by 0.5 seconds so all readers don't poll simultaneously:

```ini
[nfc_gate lane0]
startup_polling:    1
startup_poll_delay: 0.0

[nfc_gate lane1]
startup_polling:    1
startup_poll_delay: 0.5

[nfc_gate lane2]
startup_polling:    1
startup_poll_delay: 1.0

[nfc_gate lane3]
startup_polling:    1
startup_poll_delay: 1.5
```

---

## Next Steps

- [Spoolman Integration](../shared/spoolman-integration.md) — register your tag UIDs
- [Commands & Macros](../shared/klipper-functions.md) — full command reference
- [Configuration Reference](../shared/configuration.md) — tune polling, logging, and timing

---

*Copyright (C) 2026 WoodWorker. Licensed under [GPL-3.0-or-later](https://www.gnu.org/licenses/gpl-3.0.html) — see [LICENSE](../../LICENSE).*

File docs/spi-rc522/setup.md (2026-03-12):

# SPI / RC522 — Setup & Deployment

[← Back to Index](../../Readme.md)

---

## Hardware Path: SPI / RC522

Use this path when you have a **dedicated Raspberry Pi Pico** connected to the CAN bus
with RC522 NFC readers wired to its SPI1 bus.

**You do NOT need this path** if your EMU gates are wired to EBB42 lane boards with PN532
readers — use the [I2C / PN532 path](../i2c-pn532/setup.md) instead.

---

## Prerequisites

- Klipper installed on a Raspberry Pi (klippy running)
- CAN bus working (e.g. with an EBB36/42 toolhead board already on the bus)
- Raspberry Pi Pico + SN65HVD230 CAN transceiver, wired per [wiring.md](wiring.md)
- RC522 modules wired to Pico SPI1 per [wiring.md](wiring.md)

---

## Step 1 — Install from Git

Clone the repository and run the install script. The script creates symlinks from the
repo into Klipper's extras directory — future `git pull` updates take effect after a
Klipper restart, with no re-install needed.

```bash
cd ~
git clone YOUR_REPO_URL_HERE emu-nfc-reader
bash ~/emu-nfc-reader/install.sh
```

Verify the symlinks were created:

```bash
ls -la ~/klipper/klippy/extras/nfc_gates
ls -la ~/klipper/klippy/extras/nfc_gate.py
```

Both should point back into `~/emu-nfc-reader/`.

---

## Step 2 — Build Klipper MCU Firmware for the Pico

```bash
cd ~/klipper
make menuconfig
```

Select these options:

| Setting | Value |
|---|---|
| Micro-controller | Raspberry Pi RP2040 |
| Communication interface | CAN bus |
| CAN TX GPIO | 4 |
| CAN RX GPIO | 5 |
| CAN bus speed | 1000000 (1 Mbit/s) |

Then build:

```bash
make clean && make
```

Output firmware: `out/klipper.uf2`

> SPI pin assignments are **not** set in `make menuconfig`. They are configured at
> runtime by Klipper's `MCU_SPI` interface using the `cs_pin` and `spi_bus` keys
> in `nfc_gates_spi_rc522.cfg`.

---

## Step 3 — Flash the Pico

Hold **BOOTSEL** and connect the Pico to the Pi via USB:

```bash
cp out/klipper.uf2 /media/$USER/RPI-RP2/
```

The Pico reboots automatically into Klipper MCU firmware and appears on the CAN bus.

If the Pico is already on CAN running an older Klipper build:

```bash
python3 ~/klipper/scripts/flash_can.py -u <current_uuid> -f out/klipper.uf2
```

---

## Step 4 — Find the Pico CAN UUID

```bash
~/klippy-env/bin/python ~/klipper/scripts/canbus_query.py can0
```

Expected output:

```
Found canbus_uuid=aabbccddeeff, Application: Klipper
```

Note the UUID — you will paste it into the config in the next step.

---

## Step 5 — Configure printer.cfg

Copy both config files to your Klipper config directory:

```bash
cp ~/emu-nfc-reader/config/nfc_macros.cfg           ~/printer_data/config/
cp ~/emu-nfc-reader/config/nfc_gates_spi_rc522.cfg  ~/printer_data/config/
```

Add both includes to `printer.cfg`:

```ini
[include nfc_macros.cfg]
[include nfc_gates_spi_rc522.cfg]
```

`nfc_macros.cfg` contains the Happy Hare integration macros (`_NFC_SPOOL_CHANGED` etc.)
and is shared between the SPI and I2C paths. Edit it to customise the GCode if needed.

Edit `~/printer_data/config/nfc_gates_spi_rc522.cfg` and make these changes:

| Key | What to do |
|---|---|
| `canbus_uuid` | Replace `YOUR_UUID_HERE` with the UUID from Step 4 |
| `extra_cs_pins` | Remove entries for gates you don't have wired |
| `poll_interval` | Leave at `30` for production; reduce to `5` for initial testing |

---

## Step 6 — Set Up Moonraker Auto-Update

Add this section to `~/printer_data/config/moonraker.conf`:

```ini
[update_manager emu_nfc_reader]
type: git_repo
path: ~/emu-nfc-reader
origin: YOUR_REPO_URL_HERE
primary_branch: main
managed_services: klipper
install_script: install.sh
```

Restart Moonraker:

```bash
sudo systemctl restart moonraker
```

Updates will now appear in the Mainsail / Fluidd update panel alongside Klipper itself.
Moonraker runs `install.sh` after each update to refresh the symlinks, then restarts Klipper.

---

## Step 7 — Restart Klipper and Verify

```bash
sudo systemctl restart klipper
```

Check the log for successful initialisation:

```bash
tail -f ~/printer_data/logs/klippy.log | grep nfc_gates
```

Expected output:

```
nfc_gates: connected to MCU 'nfc_pico', initialising 5 gates (poll=30s, absent_threshold=3)
nfc_gates: gate 0 RC522 init OK (TxControl=0x83)
nfc_gates: gate 1 RC522 init OK (TxControl=0x83)
nfc_gates: gate 2 RC522 init OK (TxControl=0x83)
nfc_gates: gate 3 RC522 init OK (TxControl=0x83)
nfc_gates: gate 4 RC522 init OK (TxControl=0x83)
nfc_gates: 5/5 readers initialised
nfc_gates: polling thread started
```

If any reader fails: `nfc_gates: gate N reader did not respond after init (check wiring)`
— see [Troubleshooting](troubleshooting.md).

---

## Step 8 — Test Tag Detection

From the Klipper console (Mainsail / Fluidd terminal):

```
NFC_GATE_STATUS
```

All gates should show `empty` before any tags are placed.

Place an NFC spool tag on Gate 0. Within one poll cycle (30 s, or 5 s if you reduced it):

```
NFC gate 0: spool 1042 detected (UID A3F200CC)
```

Remove the tag. After 3 missed polls (90 s at the default 30 s interval):

```
NFC gate 0: spool removed
```

If you see `has no spool ID`, the tag has not been written yet.
See [Writing Spool IDs to NFC Tags](../shared/tag-writing.md).

---

## Updating the Module

With Moonraker configured (Step 6), updates appear in the update panel automatically.

To update manually:

```bash
cd ~/emu-nfc-reader
git pull
bash install.sh
sudo systemctl restart klipper
```

---

**Next:** [Wiring Diagram →](wiring.md) | [Troubleshooting →](troubleshooting.md)

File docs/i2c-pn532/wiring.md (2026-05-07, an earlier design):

# Wiring the PN532

[← README](../../Readme.md) | [Next: Install →](../shared/install-uninstall.md)

Each filament gate gets **one PN532 wired directly to that gate's EBB42**. There is no shared bus — each reader lives on its own lane MCU's I2C bus.

```
lane0 EBB42  ←I2C→  PN532 (gate 0)
lane1 EBB42  ←I2C→  PN532 (gate 1)
lane2 EBB42  ←I2C→  PN532 (gate 2)
  ...
```

---

## Before You Wire Anything

> [!IMPORTANT]
> **Set the PN532 to I2C mode first, before connecting any wires.** The mode is selected by two jumpers or DIP switches on the PN532 board (labeled SEL0/SEL1, or sometimes A0/A1). If the mode is wrong, the reader will not respond on the I2C bus — and the symptoms look exactly like a wiring fault.

| Mode | SEL0 | SEL1 |
|---|:---:|:---:|
| SPI | 0 | 0 |
| **I2C ← set this** | **1** | **0** |
| UART / HSU | 0 | 1 |

Set **SEL0 = 1, SEL1 = 0**. Check your board's silkscreen — some boards number the switches in reverse, or label them differently. When in doubt, check the NXP PN532 datasheet (UM10232), Table 3.

---

## Soldering the PN532

The PN532 antenna pads are fragile — the copper ring on the top (antenna) side will lift off the board if overheated. Always solder from the back.

**Method:**

1. Insert the wire from the **back** of the board so it pokes through the hole toward the antenna side.
2. Apply the iron to the back of the board. Let solder pool up on the back pad.
3. Feed enough solder that the pool flows **through the hole** and wets the antenna-side ring — you should see a small fillet appear on the top.
4. Remove heat immediately once the solder flows through. Lingering heat is what lifts the antenna-side ring.

> [!WARNING]
> **Never apply the iron directly to the antenna-side pad.** The copper ring on the top of the board is bonded to a thin substrate and will delaminate with sustained heat. If the ring lifts, the mechanical connection is gone even if the hole still looks filled.

A proper joint: solder pool visible on the back, small filled fillet on the antenna side, wire cannot be pulled out by hand.

---

## Pin Connections

Connect each PN532 to its lane's EBB42 using these four wires:

```
EBB42 Pin       →    PN532 Module
──────────────────────────────────
PB3  (I2C SCL)  →    SCL
PB4  (I2C SDA)  →    SDA
3V3             →    VCC  (or the 3.3V pad if your board has both)
GND             →    GND
```

> [!WARNING]
> **3.3V logic only on SDA and SCL.** Some PN532 breakout boards accept 5V on the VCC pin through an onboard regulator, but the I2C signal lines must be 3.3V. The EBB42 is a 3.3V device. Never connect 5V to PB3 or PB4.

The matching Klipper config for these pins:

```ini
[nfc_gate lane0]
i2c_mcu: lane0
i2c_bus: i2c3_PB3_PB4
```

---

## I2C Address

The PN532 I2C address is **fixed at `0x24` (decimal `36`)** by the chip — it cannot be changed. The two pads/jumpers on the breakout board (SEL0/SEL1, sometimes labeled A0/A1) select the **communication protocol**, not the address. For I2C you must have SEL0=1, SEL1=0 (see the mode table above).

The address is set in `nfc_reader.cfg`:

```ini
[nfc_gate]
i2c_address: 36    ; fixed — 36 = 0x24, do not change
```

---

## Sharing the Bus with a BME280

The EBB42 typically has a BME280 temperature/humidity sensor on the same PB3/PB4 bus. This is fine — the PN532 (`0x24`) and BME280 (`0x76`) have different addresses and coexist without conflict.

> [!NOTE]
> If the BME280 worked before you added the PN532 and now fails, it is almost always a physical issue — the PN532 is in SPI or UART mode and disrupting the bus, or there is a wiring problem. See [Troubleshooting: BME280 fails after PN532 is added](troubleshooting.md#bme280-fails-after-pn532-is-added).

---

## Pull-up Resistors

I2C needs pull-up resistors on SDA and SCL. Most PN532 breakout boards include 10kΩ pull-ups, and the EBB42 also has its own. These typically work fine together.

If you add more boards (each with their own pull-ups), the parallel resistance drops and can cause marginal signaling:

- 2× 10kΩ boards in parallel → 5kΩ — fine
- 3× boards → ~3.3kΩ — usually fine
- 6+ boards → ~1.7kΩ — may be too strong

If you suspect pull-up issues: remove or bridge (disable) the PN532 board's onboard resistors and rely on the MCU's pull-ups alone.

---

## Wire Length

Keep wires short for initial bring-up — under 20cm if possible. Longer cables add capacitance that rounds signal edges, which makes marginal timing worse.

Once confirmed working, cables up to ~50cm are usually fine at 400kHz. If you see intermittent failures with longer cables, drop the I2C speed:

```ini
[nfc_gate lane0]
i2c_speed: 100000    ; 100kHz instead of 400kHz
```

---

## Bring-Up Order

Follow this sequence to avoid chasing phantom failures:

1. Confirm Happy Hare sees the lane MCU normally (no PN532 connected yet)
2. If a BME280 is fitted, confirm it reads correctly before touching anything
3. Set the PN532 DIP switches to I2C mode (SEL0=1, SEL1=0)
4. Connect VCC and GND
5. Connect SDA and SCL
6. Restart Klipper
7. Run `NFC GATE=0 INIT=1`
8. If INIT passes, run `NFC GATE=0 SCAN=1` with a tag nearby

If the BME280 breaks only after the PN532 is connected, the fault is physical — mode selection, swapped SDA/SCL, or pull-up interaction. It is not a Spoolman or Happy Hare issue.

---

*Copyright (C) 2026 WoodWorker. Licensed under [GPL-3.0-or-later](https://www.gnu.org/licenses/gpl-3.0.html) — see [LICENSE](../../LICENSE).*

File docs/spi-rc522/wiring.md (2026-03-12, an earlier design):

# SPI / RC522 — Wiring Diagram & Pin Reference

[← Back to SPI Setup](setup.md) | [← Back to Index](../../Readme.md)

---

## Overview

One **Raspberry Pi Pico** connects to the CAN bus and hosts up to 8 RC522 readers
on its hardware SPI1 bus. All readers share SCK, MOSI, MISO, RST, VCC, and GND.
Each reader has its own CS (chip-select) GPIO.

---

## CAN Bus Transceiver

The Pico cannot drive CAN bus directly. A 3.3V CAN transceiver module
(e.g. SN65HVD230) is required between the Pico GPIO and the CAN bus differential pair.

> Use a **3.3V** transceiver. Do **not** use a 5V module (e.g. MCP2551) —
> the Pico's GPIO is not 5V tolerant.

> Tie the transceiver's RS / slope-control pin to GND for high-speed mode
> (required at 1 Mbit/s).

> The CAN bus must be terminated with 120 Ω between CANH and CANL at each physical
> end of the bus. Most EBB toolhead boards have a termination jumper for one end.

```
Raspberry Pi Pico          SN65HVD230
┌─────────────┐            ┌──────────────────┐
│  GP4 (TX) ──┼────────────┼─► TXD            │
│  GP5 (RX) ──┼────────────┼─◄ RXD            │
│  3V3 OUT  ──┼────────────┼─► VCC (3.3V)     │
│  GND      ──┼────────────┼─► GND            │
└─────────────┘            │   CANH ──────────┼──► CAN bus (CANH)
                           │   CANL ──────────┼──► CAN bus (CANL)
                           └──────────────────┘
```

---

## Full Wiring Diagram (5-gate example)

```
Raspberry Pi Pico
┌──────────────────────────────────────────┐
│                                          │
│  GP4 (CAN TX) ────────────────────────── TXD  SN65HVD230
│  GP5 (CAN RX) ────────────────────────── RXD  SN65HVD230
│                                          │
│  GP0  ──────────────────────────────── SDA  RC522 Gate 0
│  GP1  ──────────────────────────────── SDA  RC522 Gate 1
│  GP2  ──────────────────────────────── SDA  RC522 Gate 2
│  GP3  ──────────────────────────────── SDA  RC522 Gate 3
│  GP6  ──────────────────────────────── SDA  RC522 Gate 4
│                                          │
│  GP7  ─────────────────────────┬──────── RST  RC522 Gate 0
│  (or tie RST to 3V3)           ├──────── RST  RC522 Gate 1
│                                ├──────── RST  RC522 Gate 2
│                                ├──────── RST  RC522 Gate 3
│                                └──────── RST  RC522 Gate 4
│                                          │
│  GP8  (SPI1 MISO) ─────────────┬──────── MISO RC522 Gate 0
│                                ├──────── MISO RC522 Gate 1
│                                ├──────── MISO RC522 Gate 2
│                                ├──────── MISO RC522 Gate 3
│                                └──────── MISO RC522 Gate 4
│                                          │
│  GP10 (SPI1 SCK)  ─────────────┬──────── SCK  RC522 Gate 0
│                                ├──────── SCK  RC522 Gate 1
│                                ├──────── SCK  RC522 Gate 2
│                                ├──────── SCK  RC522 Gate 3
│                                └──────── SCK  RC522 Gate 4
│                                          │
│  GP11 (SPI1 MOSI) ─────────────┬──────── MOSI RC522 Gate 0
│                                ├──────── MOSI RC522 Gate 1
│                                ├──────── MOSI RC522 Gate 2
│                                ├──────── MOSI RC522 Gate 3
│                                └──────── MOSI RC522 Gate 4
│                                          │
│  3V3 OUT ──────────────────────┬──────── VCC  RC522 Gate 0
│                       (also ──►│ VCC SN65HVD230)
│                                ├──────── VCC  RC522 Gate 1
│                                ├──────── VCC  RC522 Gate 2
│                                ├──────── VCC  RC522 Gate 3
│                                └──────── VCC  RC522 Gate 4
│                                          │
│  GND ──────────────────────────┬──────── GND  RC522 Gate 0
│                       (also ──►│ GND SN65HVD230)
│                                ├──────── GND  RC522 Gate 1
│                                ├──────── GND  RC522 Gate 2
│                                ├──────── GND  RC522 Gate 3
│                                └──────── GND  RC522 Gate 4
└──────────────────────────────────────────┘
```

---

## Pin Reference Table

| Pico GPIO | Function | Connected To | Notes |
|---|---|---|---|
| GP0 | RC522 CS (Gate 0) | RC522 Gate 0 SDA | Chip select — active low |
| GP1 | RC522 CS (Gate 1) | RC522 Gate 1 SDA | Chip select — active low |
| GP2 | RC522 CS (Gate 2) | RC522 Gate 2 SDA | Chip select — active low |
| GP3 | RC522 CS (Gate 3) | RC522 Gate 3 SDA | Chip select — active low |
| **GP4** | **CAN TX** | **SN65HVD230 TXD** | **CAN bus transmit** |
| **GP5** | **CAN RX** | **SN65HVD230 RXD** | **CAN bus receive** |
| GP6 | RC522 CS (Gate 4) | RC522 Gate 4 SDA | Chip select — active low |
| GP7 | RC522 RST | All RC522 RST | Shared reset — or tie all RST to 3V3 |
| GP8 | SPI1 MISO | All RC522 MISO | Shared data in |
| GP10 | SPI1 SCK | All RC522 SCK | Shared clock — 1 MHz |
| GP11 | SPI1 MOSI | All RC522 MOSI | Shared data out |
| 3V3 OUT | — | RC522 VCC + transceiver VCC | 3.3V rail — do not use 5V |
| GND | — | RC522 GND + transceiver GND | Common ground |

---

## RC522 Module Pinout

Each RC522 board has 8 pins:

| RC522 Pin | Function | Connect to |
|---|---|---|
| VCC | Power | Pico 3V3 OUT |
| GND | Ground | Pico GND |
| RST | Reset (active low) | Pico GP7 — or tie to 3V3 |
| SDA | SPI Chip Select | Unique Pico GPIO per gate (GP0–GP6) |
| SCK | SPI Clock | Pico GP10 (shared) |
| MOSI | SPI data out from Pico | Pico GP11 (shared) |
| MISO | SPI data in to Pico | Pico GP8 (shared) |
| IRQ | Interrupt | Not used — leave unconnected |

> **Voltage:** RC522 modules run at 3.3V. The Pico's GPIO is 3.3V native — no level
> shifters required. Do **not** connect RC522 VCC to the Pico's VBUS (5V) pin.

---

## Notes on Shared Lines

SCK, MOSI, MISO, RST, VCC, and GND are shared across all RC522 modules.
Only the SDA (CS) line is unique per module — daisy-chain the shared lines across
all boards and run individual wires only for SDA.

**RST pin:** A hardware reset pulse is not required. The software init sequence sends
a `PCD_RESETPHASE` command over SPI to soft-reset each reader. You can tie all RC522
RST pins directly to 3.3V (permanently deasserted). If you do wire RST to GP7,
configure it as a static high output — no toggling is needed.

**RF isolation:** All RC522 antenna coils are powered simultaneously. The CS pin
provides software isolation only — only one reader is selected on SPI at a time.
For physical RF isolation between adjacent gates, maintain at least **3 cm** separation
between antenna coils, or use ferrite backing behind each antenna.

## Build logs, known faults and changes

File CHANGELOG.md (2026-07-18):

# Changelog

All notable changes to the EMU NFC Gate Reader are documented here.
Format follows [Keep a Changelog](https://keepachangelog.com/en/1.1.0/).

**Legend:** ✨ Added · 🐛 Fixed · ♻️ Changed · 📝 Docs · ✅ Verified · 💡 Note

---

## [1.3.1] - 07/17/2026 - WoodWorker

### Scan-Jog Rewind LED Release Cleanup

- 🐛 **Fixed lane LEDs sticking in the rewind effect after scan-jog** — NFC now
  releases the temporary rewind LED for the active gate immediately after the
  fast rewind-to-buffer move completes, before handing filament parking back
  to Happy Hare via `_MMU_STEP_UNLOAD_GATE`.
- ♻️ **Per-gate LED release is now explicit** — Happy Hare v3 release now sends
  `MMU_SET_LED GATE=<gate> EXIT_EFFECT=gate_status FADETIME=0` before the
  quiet gate-map refresh, so the lane returns to Happy Hare's normal
  gate-status display instead of relying on a global `MMU_GATE_MAP QUIET=1`
  repaint to clear the temporary effect.
- 🐛 **Prevented the cleanup release from causing a second LED blink** — scan
  jog tracks whether the rewind LED was already released for the current
  cycle. The end-of-scan cleanup now retries only if the earlier release
  failed, avoiding a sloppy-looking second repaint in the normal path.
- ♻️ **Happy Hare v4 release remains direct-effect based** — per-gate release
  now removes only the tracked NFC lane effect for that gate, while full
  release still stops every tracked NFC direct effect and refreshes the gate
  map.

## [1.3.0] - 07/15/2026 - WoodWorker

### NFC_DOCTOR Virtual Endstop Visibility + ENDSTOP=ADD Insertion Fix

- ✨ **Per-lane virtual endstop status in `NFC_DOCTOR`** — each enabled gate's
  line now ends with `virtual_endstop: Loaded` or `Unloaded`
  (`_nfc_endstop_status_text()` in `nfc_manager.py`), reading directly off
  `printer.lookup_object("mmu_nfc_endstop laneN")` so a missing or
  not-yet-restarted endstop is visible on the same line as the gate itself,
  not just in the aggregate summary below.
- 🐛 **Fixed `NFC_DOCTOR GATE=<#> ENDSTOP=ADD` inserting in the wrong spot** —
  `_insert_nfc_endstop_after_lane()` searched only for the next `[section]`
  header as a stopping point, so it skipped over the next lane's comment
  banner (e.g. `# ===== LANE 2 =====`) and dropped the new
  `[mmu_nfc_endstop laneN]` block after the banner instead of before it. It
  now also stops at the first blank line, matching where the block sits in
  the shipped `nfc_reader_hw.cfg` template.
- ♻️ **Removed the Happy Hare version compatibility line from `NFC_DOCTOR`** —
  that check (scan-jog `action=idle`/`action=checking` support) belongs to
  scan-jog's own gating logic, not doctor's config/reader/Spoolman scope.
- 📝 **`NFC_HELP` updated** to mention virtual endstop checking under the
  `NFC_DOCTOR` entry.

## [1.2.0] - 07/11/2026 - WoodWorker

### TigerTag Left-Neighbor Interference Detection

Left-neighbor interference detection (shifting an adjacent gate's spool out
of the reader field when its tag is misread as the current gate's) only
worked for Bambu tags, since Bambu is the only supported format that ships
two physical tags per spool — the only case where a plain UID comparison
against the neighbor's cache can't tell "same spool, other side's tag" apart
from "genuinely different spool."

- ✨ **Twin Tag ID extraction** — `_try_tigertag()` (`vendor/rfid_tag_parser.py`)
  now reads a 4-byte big-endian field at offset `+32` (page `0x0C`), written
  identically to both physical tags when a spool's left/right sides are
  programmed together. Stored as `info["tigertag_twin_tag_id"]`.
- ✨ **Wired into `spool_identity`** as `"tigertag_%d" % twin_tag_id`, the same
  field Bambu populates from `tray_uid` as `"bambu_%s" % tray_uid`. No
  changes needed in `scan_jog.py`: the existing `current_spool_identity()` /
  `spool_identity_for_gate()` / `is_left_neighbor_spool_identity_match()`
  chain compares `spool_identity` generically, with no awareness of which
  parser produced it — so TigerTag spools with matching Twin Tag IDs on
  adjacent gates now get the same automatic clearance jog Bambu spools
  already had.
- 💡 **No new tag reads required** — the twin tag ID falls within the 64 bytes
  (`tag_max_pages: 16` default) already fetched per read. `_try_tigertag()`
  previously stopped parsing at offset 31 even though the bytes past it were
  already present in its `raw` buffer.
- ✅ **Confirmed, not inferred** — TigerTag's own published RFID guide documents
  a genuine two-tags-per-spool design with this field as the same-spool
  pairing key.

### QIDI Box / Creality CFS Default-Key MIFARE Fallback Enabled

Rich reads for any non-Bambu MIFARE Classic tag (QIDI Box, Creality CFS)
never actually worked: `read_current_tag()` (`tag_handler.py`) only ever
tried Bambu's own HKDF-derived keys, and the intended default-key retry for
everyone else existed in the file but was commented out pending hardware
confirmation.

- ✅ **QIDI Box key confirmed** — the plain MIFARE Classic factory default Key
  A, `FF FF FF FF FF FF`. Not a secret; sourced from the community
  `TinkerBarn/BoxRFID-Touch` project (same PN532 chip family this project
  already uses), which authenticates block 4 with this exact key before
  reading/writing material/color/manufacturer codes. Creality CFS's real key
  turned out to be neither the default key nor a simple custom key — see
  "Creality CFS/K1/K2 AES Tag Support" below.
- 🐛 **QIDI material lookup aligned to QIDI's RFID guide** — corrected the
  QIDI material code table used by `_try_qidi_box()` so codes 42-50 match
  the official wiki values (`PETG-CF`, `PETG-GF`, `PPS-CF`, `TPU`, etc.)
  and wiki-reserved/blank codes remain reported as `Unknown(n)`. Parsed QIDI
  metadata now also keeps the raw `material_code`, `color_code`, and
  `manufacturer_code` for debugging real tags.
- ✨ **Creality spool identity added for left-neighbor checks** — `_try_creality_tag()`
  now hashes the parsed structured payload fields
  `vendor_id:date_code:batch:filament_id:color:length:serial` into a compact
  decimal value and exposes it as `spool_identity = "creality_<digits>"`.
  The UID is deliberately not part of this value because `spool_identity`
  represents same-spool identity, not same-chip identity. The readable seed
  and numeric value are kept in metadata/debug output as
  `creality_identity_seed` and `creality_identity_numeric`.
- 📝 **Documented same-spool identity support** — README and shared docs now
  describe the Bambu-style `spool_identity` model for Bambu, TigerTag, and
  Creality rich tags, including the Creality payload fields used and the
  fact that Creality support has been tested against real spool tags.
- 🐛 **Scan-jog now preserves stashed spool identity** — the continuous-scan
  fast path that reuses a previously resolved UID now carries the previous
  `spool_identity` along with the spool id, and level-3 logs show both the
  current lane identity and the left lane identity used for interference
  decisions. When the pending UID matches the stashed UID, scan-jog now tries
  Spoolman UID lookup before accepting the stashed spool id; if the lookup
  has no cached `spool_identity`, it forces the rich tag parse so manufacturer
  `spool_identity` is populated before any auto-create path.
- 🐛 **Spoolman UID matches no longer suppress scan-mode identity parsing** —
  during scan-jog, an early Spoolman UID match still supplies the spool id,
  but structured tag reading continues so Bambu/Creality/TigerTag
  `spool_identity` is cached on the gate for left-neighbor comparisons.
- 🐛 **Spoolman-resolved NTAGs no longer burn decode retries** — after the
  initial scan-mode identity parsing change, any `tag_parsing: True` read
  that resolved through Spoolman could still be forced down the rich-read
  path when `spool_identity` was missing. That caused ordinary NTAG /
  UID-registered spools to run the 5-position decode retry loop even though
  the UID had already resolved to a valid Spoolman spool. Scan-jog and the
  early UID lookup now force rich parsing only when the resolved Spoolman
  spool matches the left neighbor's cached spool, which is the case where a
  manufacturer `spool_identity` is needed to confirm left-neighbor
  interference. Clean Spoolman UID hits for other spools now resolve
  immediately.
- 🐛 **Manufacturer identity is checked before auto-create** — after rich tag
  metadata is parsed and Spoolman UID lookup misses, scan mode compares the
  current tag's `spool_identity` against the left gate before allowing
  metadata-direct or auto-created spool resolution to continue.
- 🐛 **Left-neighbor clearance resumes with a fresh lane scan** — after a
  left-neighbor interference hit, scan-jog now clears stale UID/continuous
  hit-window state and resets the current lane's scan-local state as if a new
  `JOG_SCAN=1` had been issued after shifting the left lane, instead of
  reprocessing the same false read.
- 🐛 **Default-key retry enabled and restructured** in `read_current_tag()`.
  Previously it only fired if Bambu key *derivation* succeeded and then
  every sector's *authentication* failed — meaning it silently never ran at
  all for anyone without `pycryptodome` installed, since derivation itself
  would fail first and return before the retry was ever reached. The trigger
  is now "Bambu didn't produce a usable read, for any reason" (derivation
  failure or all-sectors-auth-failure), so QIDI/Creality reads work
  correctly even with `pycryptodome` absent — appropriate, since the
  default-key path needs no cryptography library at all.
- 💡 **No changes needed in `parse_tag()`** — the MIFARE block-dict →
  flat-buffer conversion that feeds `_try_qidi_box()`/`_try_creality_cfs()`
  already existed and was already correct; the only missing piece was ever
  reaching it with a second, correct key.
- 💡 **`bambu_reads: True` stays the single gate** for all authenticated MIFARE
  Classic attempts (Bambu's own keys and the default-key fallback alike) —
  left unrenamed despite now covering more than Bambu, since renaming a
  public config key is a breaking change out of scope here. `pycryptodome`
  remains required only for Bambu's own reads.
- 📝 **Documented** the confirmed QIDI key value and the (at the time)
  unconfirmed Creality status in `docs/shared/configuration.md`,
  `docs/shared/spoolman-integration.md`, and `Readme.md`.

### Creality CFS/K1/K2 AES Tag Support

The default-key retry above never worked for genuine Creality tags: unlike
QIDI Box, Creality's tag encoder derives a per-UID MIFARE Key B and encrypts
the payload itself, so both Bambu's Key A and the plain default key fail on
sector 1. This closes out the "unconfirmed" status from the previous entry.

**MIFARE Classic key attempts, in order** (`read_current_tag()` in
`tag_handler.py`), each only firing when the previous one authenticated
nothing:

| Order | Scheme | Sectors | Key type | Extra dependency |
|---|---|---|---|---|
| 1 | Bambu HKDF-derived | 0-4 | Key A | `pycryptodome` |
| 2 | MIFARE factory default (QIDI Box) | 0-4 | Key A (`FF FF FF FF FF FF`) | none |
| 3 | Creality UID-derived | 1 only | Key B | `pycryptodome` |

Each retry re-selects the same UID via the new `_retarget_same_uid()` helper
before authenticating, since a completed `mifare_read_authenticated_blocks()`
call always releases the target.

- ✨ **Key derivation and decryption** — added `_creality_derive_key_b()`
  (`vendor/rfid_tag_parser.py`): the sector-1 MIFARE Key B is
  `AES-128-ECB(AES_KEY_GEN, uid repeated to 16 bytes)[:6]`.
  `_creality_decrypt_tag_data()` then decrypts the 48-byte ASCII payload
  stored across blocks 4-6 with a second static key, `AES_KEY_CIPHER`. Both
  keys and the derivation procedure are community-sourced from a Creality
  RFID encryption helper script that mirrors the JavaScript implementation
  used by Creality's own tag-writer tooling; no code was copied, only the
  two key constants and the encrypt/decrypt procedure they document.
  ✅ Verified against the reference script's own key-generation and
  encrypt/decrypt output before wiring in. Hex/ASCII values for both keys
  are published in `docs/shared/spoolman-integration.md` (Creality key
  material table) — neither is a secret withheld from the docs.
- ✨ **New parser** — added `_try_creality_tag()` (structured like
  `_try_tigertag()`) that decrypts and field-splits the payload: batch,
  production date code, vendor ID, filament ID / material code (mapped via
  `_CREALITY_MATERIAL_MAP`), color, spool weight (via
  `_CREALITY_LENGTH_TO_WEIGHT_G`), and serial. Registered in `parse_tag()`
  under the authenticated block-dict branch, tried right after Bambu's block
  layout, returning `tag_format: "creality"`. The old `_try_creality_cfs()`
  hex-ASCII heuristic (unauthenticated, unconfirmed, `tag_format:
  "creality_cfs"`) is kept as a fallback for raw dumps but is no longer the
  primary Creality path.
- 🐛 **Creality payload slicing aligned to `DnG-Crafts/K2-RFID`** — the AES
  parser now treats the decrypted payload as
  `date + vendor_id + batch + filament_id + color + length + serial + reserve`.
  The on-tag `filament_id` is preserved, while its trailing 5-character
  material code is still used for `_CREALITY_MATERIAL_MAP` lookup. The common
  vendor ID `0276` resolves to `Creality`; the raw ID is also stored as
  `creality_vendor_id` and the legacy `creality_supplier` alias.
- 📝 **Creality level-4 decode instrumentation** — when `debug: 4` is enabled,
  `_try_creality_tag()` now traces encrypted blocks 4-6, the decrypted payload
  as hex and printable ASCII, each parsed field, lookup results, and the exact
  reject reason when a real tag does not match the expected layout.
- 🐛 **Creality parser now ignores trailing non-ASCII bytes after the 40-byte
  structured payload** — real tag reads can decrypt to valid
  `date/vendor/batch/filament/color/length/serial/reserve` data followed by
  non-ASCII trailing bytes in the remaining encrypted block space. The parser
  now decodes only the structured first 40 bytes and logs trailing bytes at
  level 4 instead of rejecting the whole tag.
- ✨ **Key B support added to all three reader drivers** —
  `mifare_read_authenticated_blocks()` gained a `use_key_b` parameter in
  `pn532_driver.py`, `pn7160_driver.py`, and `rc522_driver.py`, threaded down
  to the existing per-driver `mifare_authenticate(..., use_key_b=...)`. None
  of them exposed Key B auth through the block-read path before this, only
  Key A.
- ♻️ **`capture_mifare_metadata()` generalized** (`tag_handler.py`) — gained
  `sectors` and `use_key_b` parameters (defaulting to the previous
  sectors-0-4/Key-A behavior) so the new Creality attempt can authenticate
  sector 1 only, with Key B, without touching the Bambu/QIDI code paths.

### 📋 PR Summary

*(Copy/paste the section below into the pull request description.)*

> ## TigerTag twin-tag pairing + Creality CFS/K1/K2 AES tag support
>
> ### Summary
> - ✨ TigerTag: extract the Twin Tag ID field and feed it into `spool_identity`, extending left-neighbor interference detection (previously Bambu-only) to TigerTag's two-tags-per-spool design — no `scan_jog.py` changes needed.
> - 🐛 Re-enabled the QIDI Box / Creality default-key MIFARE fallback that existed commented-out in `read_current_tag()`, and fixed its trigger condition so it also runs when `pycryptodome` isn't installed. ✅ Confirmed correct for QIDI Box against the community `BoxRFID-Touch` reference.
> - ✨ Added full Creality CFS/K1/K2 support: UID-derived MIFARE Key B + AES-128-ECB payload decryption (`_creality_derive_key_b()`, `_creality_decrypt_tag_data()`, `_try_creality_tag()`), with `use_key_b` support added to all three reader drivers (PN532, PN7160, RC522) to make sector-1 Key B auth possible. Key material verified against the community reference script and published in the docs.
>
> ### Test plan
> - [x] `python3 -m py_compile` on all touched files
> - [x] Standalone script cross-checks `_creality_derive_key_b()` / `_creality_decrypt_tag_data()` output against the reference script's key-generation and encrypt/decrypt logic byte-for-byte
> - [x] `parse_tag()` end-to-end dispatch test confirms a synthetic Creality block dict resolves to `tag_format: "creality"` with correct material/color/weight
> - [ ] Hardware test: real TigerTag left/right pair on adjacent gates triggers automatic clearance jog
> - [ ] Hardware test: real QIDI Box tag reads material/color via the default-key fallback
> - [ ] Hardware test: real Creality CFS/K1/K2 tag reads material/color/weight via the new Key B + AES path

---

## [1.1.0] - 07/07/2026 - WoodWorker

### Virtual Endstop — Scan-Jog Now Homes to the Tag Instead of Jogging Past It

Scan-jog's forward search used to be a blind jog-then-poll loop, so the tag's
real position was only ever known as "somewhere in the last chunk."

- Added `mmu_nfc_endstop.py`, a Klipper extra that wraps an existing
  `[nfc_gate laneN]` reader as a Happy Hare gear-rail endstop
  (`mmu.gear_rail.add_extra_endstop`, standard MCU endstop interface). While
  Happy Hare homes against it, a reactor timer polls the lane's NFC reader
  every `poll_interval` (default `0.05s`) and reports triggered the instant a
  tag UID is read — no new hardware or wiring, it borrows the reader the
  matching `[nfc_gate laneN]` already owns.
- Added `[mmu_nfc_endstop laneN]` to `nfc_reader_hw.cfg` (generated
  automatically by `install.sh` for every enabled lane) and symlinked
  `mmu_nfc_endstop.py` into Klipper's extras directory.
- Both scan-jog motion modes now search with a genuine Klipper homing move
  (`_MMU_STEP_HOMING_MOVE ENDSTOP=nfc_lane<N> STOP_ON_ENDSTOP=1 MOTOR=gear`,
  or the direct `mmu.move_filament(homing_move=1, endstop_name=...)`
  equivalent) for the full remaining scan distance, instead of jogging a fixed
  chunk and polling afterward. The move physically stops the instant the
  endstop trips. `continuous` additionally polls the reader while the move is
  in flight to build a UID hit-window, used to recenter before rich tag
  parsing; `stopped` waits for the homing move to finish, then reads once.
- Continuous scan now starts by moving on the first step instead of a
  stationary 0.0 mm poll. The previously-cached UID/spool is still stashed at
  scan start, and a UID matching that stashed UID resolves directly from the
  stashed spool instead of re-running Spoolman/rich-tag resolution.
- Fixed `uninstall.sh` to also remove the `mmu_nfc_endstop.py` symlink from
  Klipper extras; it previously only cleaned up `nfc_gate.py`/`nfc_gates/`,
  leaving the endstop extra behind after uninstall.
- Documented across `Readme.md`, `docs/shared/how-it-works.md`,
  `docs/shared/klipper-functions.md`, `docs/shared/configuration.md`,
  `docs/shared/install-uninstall.md`, and `docs/shared/architecture-decisions.md`.

### Happy Hare Filament-Position Counter Drift

Repeated `JOG_SCAN=1` runs on the same lane left Happy Hare's gear position
readout (`UNLOADED N.Nmm` in the visual status banner) drifting further from
zero every cycle, because that counter is a running total that scan-jog never
re-zeroes.

- Root cause: Happy Hare's real `MMU_LOAD`/`MMU_EJECT` sequences call
  `mmu._initialize_filament_position()` (v3's monolithic `mmu.py`; v4 renamed
  it to the public `initialize_filament_position()`) once at the start,
  before any gear moves, resetting the raw driving-stepper position
  (`mmu_toolhead.get_position()[1]`) to `0.0`. Scan-jog never calls either
  sequence — it drives the gear through Happy Hare's low-level composable
  primitives (`_MMU_STEP_HOMING_MOVE`, `_MMU_STEP_MOVE`,
  `_MMU_STEP_UNLOAD_GATE`) instead, so the reset never happens on either
  Happy Hare version.
- Fixed by calling Happy Hare's position-reset method once, at the start of
  every scan-jog session (`scan_jog.start()`). `_hh_reset_filament_position()`
  tries `_initialize_filament_position` (v3) then `initialize_filament_position`
  (v4), so the fix works on either version without needing to know which is
  installed.
- Diagnosed against the wrong Happy Hare reference tree at first — an initial
  attempt targeted v4's `mmu.drive().get_filament_position()`, which doesn't
  exist on v3 (confirmed via a console diagnostic showing `has_reset_fn=False`
  against a live `mmu_found=True` install). Re-verified against the actually
  installed v3 API before landing the real fix.

### Scan-Jog Class-Level Lock Released Too Early

- Fixed `_active_scan_gate` — the "only one gate scans at a time" guard
  checked by `manual_jog_scan()` — being cleared in `finish()` and
  `rewind_and_exit()` before those functions had finished their own cleanup
  (Happy Hare dispatch, left-neighbor restore, poll resume, LED release). A
  second `JOG_SCAN=1` issued during that window could start a new scan session
  — including its own filament-position reset and gear moves — while the
  first session's Happy Hare interaction was still in flight, corrupting
  both. `_active_scan_gate = None` now runs as the last line of both
  functions, after all other cleanup.

### Happy Hare `MMU_SELECT` Visual Banner During Scan-Jog

Every scan-jog gate selection ran `MMU_SELECT GATE=<n> QUIET=1`, which printed
Happy Hare's full gate-table + visual banner on every jog regardless of
`QUIET=1` or `wrap_suppress_visual_log()`.

- Root cause: Happy Hare v3's `cmd_MMU_SELECT` selects the gate via
  `mmu.select_gate()`, then unconditionally logs the banner through
  `self.log_info(...)` — that print reads no `QUIET` parameter and is gated
  only by `mmu.log_level`, a separate switch from the `log_visual` flag that
  `wrap_suppress_visual_log()` controls.
  - A first pass temporarily zeroed `mmu.log_level` around every Happy Hare
    call scan-jog makes. It worked but was reverted as unnecessarily broad —
    it silenced all of Happy Hare's info-level logging, not just this one
    print, for the duration of every `MMU_SELECT`/`_MMU_STEP_*` call.
  - Replaced with `select_gate_quiet()`: calls `mmu.select_gate(gate_num)`
    directly through Python (the same call `cmd_MMU_SELECT` itself makes),
    falling back to the gcode form only if that method isn't available. Every
    `MMU_SELECT` gcode call in `scan_jog.py` now goes through this helper,
    mirroring the direct-Python pattern `run_direct_continuous_jog` already
    used for gate selection.
- `wrap_suppress_visual_log()` is still used for `_MMU_STEP_*` calls, where it
  correctly suppresses `_display_visual_state()` on filament-pos-state
  transitions.

---

## [1.0.0] - 07/06/2026 - WoodWorker

### Happy Hare V4 Compatibility

Two independent fixes, for two different scan-jog trigger paths, both landed on
the same underlying symptom: scan-jog could fail to start on Happy Hare v4 while
Happy Hare reports `action=checking`.

- **Automatic gate-status polling trigger** (`scan_enabled: True`, no hook):
  added Happy Hare version detection
  (`_happy_hare_version`/`_refresh_happy_hare_version`/
  `_happy_hare_major_version`, with a lazy refresh fallback if the MMU object
  was not available yet at init) and `_happy_hare_allows_scan_action()`. The
  poll timer now treats `action=checking` as scan-safe when Happy Hare reports
  major version `>= 4`; older or unknown versions still require strict
  `action=idle`.
- **Hook-triggered / manual `JOG_SCAN=1`** (`_NFC_SCAN_JOG_PRELOAD`, Happy
  Hare's `user_post_preload_extension` hook): Happy Hare v4 invokes this hook
  while still running its own load sequence, before it unwinds back to `idle`,
  so requiring strict idle there could never succeed. The macro now sends
  `NFC GATE=<n> JOG_SCAN=1 SOURCE=AUTO`; NFC only relaxes the busy check for
  calls carrying `SOURCE=AUTO` when the detected Happy Hare major version is
  `>= 4` and the action is `checking`.
  Manual/console `JOG_SCAN=1` with no `SOURCE=AUTO` is unaffected and still
  requires strict `action == idle` on any Happy Hare version.
- Fixed Happy Hare version detection to read
  `mmu.mmu_machine.happy_hare_version`, matching the current Happy Hare object
  model, while keeping the older `mmu.version` fallback.
- Added Happy Hare version reporting to `NFC_DOCTOR`, including whether v4
  `checking` scan-jog compatibility is enabled: v4 accepts `action=idle` or
  `action=checking`; v3/pre-v4 and unknown versions accept only `action=idle`.
- Documented both mechanisms in README, `docs/shared/klipper-functions.md`, and
  `docs/shared/install-uninstall.md`.

### Spoolman-Disabled Support

- Added `spoolman_url: disabled` as a valid configuration option. When set, all
  Spoolman lookup paths short-circuit cleanly (`gate._spoolman is None` guards
  are already present throughout the Python code). Tag metadata or UID-only
  resolution continues to work; the gate map and Happy Hare filament data are
  still updated via `_NFC_SPOOL_CHANGED` when `tag_parsing: True` and the tag
  carries material/color fields.
- Added `BRAND`, `MIN_TEMP`, `DIAMETER`, and `WEIGHT` parameters to the
  `_NFC_SPOOL_CHANGED` macro dispatch for the no-Spoolman (metadata-only) path.
  All four are always sent; empty string is used when the tag does not provide a
  value. `klipper_interface.py` now reads `brand`/`vendor`, `min_temp`,
  `diameter_mm`, and `weight_g`/`spool_weight_g` from the tag metadata dict.
  The macro console message displays all fields; `MMU_GATE_MAP` continues to
  receive only the fields Happy Hare supports (NAME, MATERIAL, COLOR, TEMP).
- Added `disabled` as a third Spoolman option in the installer (lane and shared
  paths). When selected the installer sets `spoolman_url: disabled`, defaults the
  tag read mode prompt to `rich` (instead of `spoolman`), prints a note
  explaining that rich mode is required to pass filament data to Happy Hare
  without Spoolman, and skips the auto-create Spoolman spool question since there
  is no Spoolman instance to create records in.
- Fixed no-Spoolman continuous scan-jog resolution. When continuous mode finds a
  UID during motion and `tag_parsing: True`, it now runs the normal rich-tag poll
  immediately after the current move completes, before scheduling the
  overshoot-backup retry. This lets metadata-only tags resolve cleanly with
  `spoolman_url: disabled` instead of backing up first because the Spoolman UID
  lookup was unavailable.

### Reader Hardware

- Added RC522 as a supported SPI reader via `reader_type: rc522`.
  `reader_factory.py` now creates an `RC522Driver` through Klipper's SPI bus
  helper before the I2C reader path. The RC522 driver exposes the current
  reader API (`read_tag(timeout=...)`, `read_target(timeout=...)`, and target
  cleanup), and honors short continuous scan probe timeouts. RC522 uses its own
  optional `rc522_transceive_delay` setting (default `0.035`) instead of
  inheriting the slower PN532 passive-target delay.
- Added RC522 ISO14443A SELECT/cascade support and NTAG/Type-2 page reads.
  `read_target()` now returns selected target info with SAK/ATQA when SELECT
  succeeds, including 4-byte, 7-byte, and 10-byte UID cascade handling. The
  driver exposes `ntag_read_page()`, `ntag_read_user_memory()`, and
  `ntag_read_ndef_user_memory()` so `tag_handler.py` can run the existing
  rich-tag metadata resolution path for RC522 Type-2 tags. If SELECT fails
  after a valid anticollision UID, the reader falls back to the existing
  UID-only target shape so Spoolman UID lookup still works. ISO15693 remains
  unsupported on RC522.
- Added MIFARE Classic authentication and block reads to the RC522 driver.
  `mifare_authenticate()` uses the RC522 hardware `MFAuthent` (0x0E) command
  which handles the three-pass challenge/response exchange internally — no
  over-the-air auth frame is sent by the host like on PN532. After auth,
  `mifare_read_block()` uses the same `_transceive_crc` path as NTAG page
  reads; `RxCRCEn` in `ModeReg` strips the two CRC trailer bytes so the FIFO
  holds only the 16 data bytes. `mifare_read_authenticated_blocks()` matches
  the PN532 return shape (`{"uid_bytes": …, "blocks": {abs_block: bytes}}`)
  so `tag_handler.py` and the Bambu parser stay reader-agnostic. The RC522
  stops on the first auth or read failure (same policy as PN7160) because the
  hardware crypto state (`MFCrypto1On`) becomes unreliable after a rejected
  handshake; `_stop_crypto1()` clears `Status2Reg` bit 3 in the `finally`
  block so subsequent scans are never left in encrypted mode. Bambu refill
  RFID tags (MIFARE Classic 1K with HKDF-derived sector keys) are now fully
  supported on RC522.
- Added RC522 diagnostic logging for the SPI path. Init failures now log a
  warning with SPI wiring/config hints before re-raising, health checks warn
  when the reader does not respond or antenna TX bits are off, and post-REQA
  anticollision/checksum failures produce warning-level summaries with raw
  detail retained behind `debug >= 4`. Manual `SCAN=1` output now handles
  UID-only targets with no SAK value.
- Added RC522-specific low-level debug commands guarded by `low_level_debug`.
  `INIT=1` and `SCAN=1` exercise the normal RC522 init and UID scan paths;
  `RC522_DUMP_REGS=1`, `RC522_REG_READ=<reg>`,
  `RC522_REG_WRITE=<reg> VALUE=<byte>`, `RC522_ANTENNA=0|1`,
  `RC522_REQA=1`/`RC522_WAKE=1`, and
  `RC522_TRANSCEIVE='<bytes>' BIT_FRAMING=<0-7>` provide register, antenna,
  FIFO transceive, and tag-wake diagnostics without reusing PN532 ACK/ready
  semantics.
- Added orchestration-facing RC522 SPI aliases for the same diagnostics:
  `RC522_REGISTER=<reg> [VALUE=<byte>]`, `RC522_ANTENNA_ENABLE=0|1`,
  `RC522_TAG_WAKE=1`, and
  `RC522_FIFO_TRANSCEIVE='<bytes>' BIT_FRAMING=<0-7>`. These run through the
  `NFC` / `NFC_SHARED` handlers, so shared-reader and per-lane RC522 debugging
  uses the same NFC Reader command surface as init and scan.

### Console Output and Logging

- Replaced all abbreviated `HH` references with `Happy Hare` across log strings, console messages, docstrings, and user-visible status text in `nfc_manager.py`, `scan_jog.py`, `shared_preload.py`, and `hh_status.py`. `HH_SYNC` macro/command names and the `HH:MM:SS` datetime format in `log.py` are unchanged.
- Changed `[SCAN]`, `[REWIND]`, and `[OK]` tagged scan-jog messages to appear at `console_log_level: 2`, matching the warning threshold. Previously all scan-jog messages required level 3. Verbose detail lines with no tag (move-queued timing, LED state changes) still require level 3.
- Gated retry-jog position detail lines (`decode retry move queued Xmm  scan position X.X / X.Xmm`) and overshoot backup position detail lines (`continuous overshoot backup queued Xmm  scan position X.X / X.Xmm`) behind `gate._debug >= 3`. The `[WARN]` tagged console messages for these same events are unaffected and remain visible at the default warning threshold.
- Changed continuous jog move logging so it reports the actual execution path:
  `Direct Move` for direct Happy Hare MMU-toolhead moves or `MMU_TEST_MOVE` for
  the G-code fallback. The user-visible `[SCAN]` move line now fires after the
  call so it accurately reflects what was executed.

### Macro Naming Consistency

- The configured lane name (e.g. `lane0` from `[nfc_gate lane0]` in `nfc_reader_hw.cfg`) is now forwarded to all three NFC event macros as a `READER=` parameter. `_NFC_SPOOL_CHANGED`, `_NFC_SPOOL_REMOVED`, and `_NFC_TAG_NO_SPOOL` use `params.READER | default('Lane' ~ gate)` so console output reads `NFC[lane0]:` matching the section name in hardware config rather than a hardcoded `NFC gate N:` format.
- Capitalized `Gate` (capital G) in the remaining user-visible macro output lines — `NFC_HH_SYNC_CACHE` sync progress and `_NFC_SCAN_UNRESOLVED` — to match the capitalization used by `NFC_STATUS`.

### Command Fixes

- Added `NFC GATE=<#> JOG_SCAN=1` to the `NFC_HELP` output. The command existed but was only documented in the per-gate `NFC GATE=<#> HELP=1` listing.
- Fixed `NFC GATE=<#> HELP=1` incorrectly triggering the low-level PN532 debug path. `low_level_debug_requested()` checks for a `HELP` parameter, so `HELP=1` was intercepted before the per-gate help handler ran, producing spurious `polling paused for low-level PN532 debug` and `low_level_debug is disabled in config` console messages. The HELP check now runs first in `cmd_NFC`.
- Corrected the help text entry from `NFC GATE=<#> HELP` to `NFC GATE=<#> HELP=1` to match the required Klipper parameter style.

### Scan-Jog Continuous Mode — Now Default

- Promoted continuous scan-jog to the default motion mode. `scan_motion_mode: continuous` is now the out-of-the-box setting in `nfc_reader.cfg` and the Python fallback default. `scan_motion_mode: stopped` remains fully supported for marginal reader or tag alignment where continuous polling misses the tag.
- Updated `docs/shared/configuration.md`, `docs/shared/klipper-functions.md`, and `docs/shared/how-it-works.md` to reflect continuous as the default and document stopped as the alternative.

- Added opt-in continuous scan-jog mode via `scan_motion_mode: continuous`.
  Continuous mode queues forward search chunks through Happy Hare's MMU toolhead
  and polls NFC while the chunk is estimated to be moving, while preserving
  existing tag-found actions, the 0.1 second read-light hold, rewind, and
  completion logic.
- Added continuous scan settings:
  `scan_continuous_step_mm`, `scan_continuous_speed`,
  `scan_continuous_accel`, and `scan_continuous_poll_interval`.
- Changed the default rich-tag decode retry spacing from 2 mm to 5 mm and added
  continuous-mode UID hit-window recentering before rich parsing/retries when a
  UID hit does not resolve through Spoolman.
- Changed continuous-mode rich tag retry jogs from a ±sweep to a two-phase
  backward/forward walk. After the initial overshoot backup, retries now:
  (1) step backward from the backup point in `scan_decode_retry_mm` increments
  (half of `scan_decode_retry_rounds` attempts, floor at 0); then
  (2) return to the backup point and step forward in the same increment toward
  the original UID detection position (ceiling = scan total before backup),
  using the remaining attempts. The backup point and UID detection position are
  recorded as `_scan_continuous_overshoot_start_mm` and
  `_scan_continuous_overshoot_origin_mm` at backup time. Both the
  `queue_continuous_overshoot_backup` and `retry_incomplete_decode` backup paths
  record these values. The `retry_incomplete_decode` function now redirects
  continuous+overshoot retries to `queue_decode_retry_move` (same path as
  no-tag-found retries) instead of falling through to the stopped-mode ±sweep.
- Fixed a race in the first continuous chunk where `mmu.select_gate()` blocks
  for the full gate-positioning time (~0.5 s) inside `run_direct_continuous_jog`.
  Because this blocking consumed more time than the expected move duration,
  `remaining_duration` was computed as zero and the code declared the first chunk
  complete before it entered the motion queue. The second chunk was then submitted
  immediately, creating a growing motion queue backlog that shifted all subsequent
  position estimates by one full chunk (75 mm). Tags were detected one chunk
  (75 mm × number of queued moves) later than their physical location. Fixed by
  detecting when gate selection ran during the call and using `expected_duration`
  rather than `max(0, expected_duration - command_elapsed)` for that call only.
- Changed in-flight continuous probe rate. `scan_continuous_poll_interval` now
  serves as the hardware probe timeout passed to `read_tag()` in addition to its
  existing role as the timer reschedule interval. The reactor now reschedules
  immediately after each in-flight probe (returning `now` rather than
  `now + poll_interval`) so the hardware timeout is the only pacing. This raises
  the probe count per chunk from ~3 to ~10–15 (depending on speed and step size),
  reducing the effective per-probe coverage from ~28 mm to ~5 mm and making
  near-edge misses much less likely.
- Added missing commands to the global `NFC_HELP` output. The following commands
  existed and worked but did not appear in the help listing:
    `NFC GATE=<#> INIT=1` — re-run reader hardware initialisation
    `NFC GATE=<#> APPLY=1` — send cached spool to Happy Hare immediately
    `NFC GATE=<#> CLEAR_CACHE=1` — clear cached spool/UID without dispatching
    `NFC GATE=<#> HH_SYNC=1 SPOOL_ID=<n>` — seed lane cache from Happy Hare gate map
- Changed continuous in-flight scanning to perform a UID-only probe while the
  chunk is moving, then defer Spoolman lookup and rich tag parsing until the
  current chunk has finished.
- Switched continuous scan behavior to try resolving a detected UID first;
  only if tag resolution fails is the reverse/overshoot backup jog queued.
- Documented the tested continuous profile: 50 mm chunks at 150 mm/s with
  2000 mm/s^2 acceleration and a 0.05 s in-flight tag-check cadence.
- Optimized the baseline continuous scan configuration for optimal speed while
  minimizing overshoot, balancing chunk pacing and probe cadence to reduce
  missed tags without introducing extra backtracking.
- Added direct Happy Hare MMU-toolhead forward jog support for continuous scan,
  with `MMU_TEST_MOVE WAIT=0` retained as a compatibility fallback.
- Reduced repeated continuous-mode search LED calls by removing the top-of-loop
  LED reapply while keeping the post-move reassertion.
- Fixed scan-jog direct console messages so they respect `console_output` and
  `console_log_level` instead of always calling `respond_info`.

---

## [0.9.23] - 06/01/2026 - WoodWorker

### Installer Prompt Cleanup

- Removed the installer terminal theme/profile prompt and the `-p` profile color option.
- Simplified installer prompt emphasis to default terminal color with bold text only; no custom cyan/green/yellow/magenta highlight colors are used.
- Added a per-lane reader I2C bus prompt. The installer now writes the selected bus to the base `[nfc_gate]`, comments/uncomments the SLB and EBB preset lines, and uses a custom active bus line when the user enters a different hardware bus.
- Added a per-lane reader MCU prefix prompt. The installer defaults to `mmu` and writes lane hardware sections as `mmu0`, `mmu1`, etc.; entering `lane` writes `lane0`, `lane1`, etc.
- Added an installer warning when software-I2C sensor config is detected in printer config files, with the hardware `i2c_bus` line users should apply to sensor sections such as `emu_macros.cfg`.
- Added optional `scan_jog_max` for scan-jog. When set, NFC uses that fixed maximum travel distance instead of reading Happy Hare Bowden calibration. The installer now asks lane-reader users whether to set `scan_jog_max` with a default of `480.0mm` or keep using per-lane Bowden lengths.

### Install / Uninstall Cutover

- Changed the public install target to `Happy-Hare-RFID-Reader` cloned into `~/rfid-reader`.
- Updated Moonraker update-manager generation to use `[update_manager Happy-Hare-RFID-Reader]`, matching the public repo name exactly.
- Added cleanup for old beta Moonraker sections: `[update_manager emu_nfc_reader]`, `[update_manager happy_hare_rfid_reader]`, and `[update_manager Happy-Hare-rfid-reader]`.
- Added beta cutover handling for legacy `~/emu-nfc-reader` installs. The installer now prompts before cleanup, backs up `~/printer_data/config/nfc/`, backs up `moonraker.conf`, removes old Klipper symlinks, removes the legacy repo, and continues with a fresh `~/rfid-reader` install.
- Removed installer-driven update behavior for existing checkouts. Users update with `git pull` before rerunning `bash install.sh`; the installer no longer runs `git pull`, `git fetch`, or sparse-checkout updates during normal installs.
- Updated uninstall behavior to prompt for local repo checkout removal at the end of `bash uninstall.sh`. The default answer is yes; answering `n` keeps `~/rfid-reader`.
- Kept uninstall repo removal guarded so it only removes the expected `~/rfid-reader` git checkout.
- Added local simulation scripts for install and uninstall testing without touching the real repo or public GitHub: `tests/simulate_rfid_reader_install.sh` and `tests/simulate_rfid_reader_uninstall.sh`.
- Updated public README, private README, install/uninstall docs, design notes, and regression tests for the new install path, uninstall prompt, Moonraker section, and public sync target.

### Scan-Jog Safety

- Blocked manual `NFC GATE=<gate> JOG_SCAN=1` when Happy Hare reports the selected gate as empty (`gate_status=0`). NFC now returns a single console error that `jog_scan` is not enabled for an empty gate and does not start motion.
- Changed normal scan-jog rewind/no-tag status messages back to `[REWIND]`/`[OK]` severity so ordinary rewind flow is not reported as `[WARN]`.
- Changed `_NFC_TAG_NO_SPOOL` console guidance to use a red `[ERROR]` heading while keeping the message in the macro alongside the Happy Hare gate-map cleanup.

### Shared Reader Bypass

- Moved the bypass active-spool console confirmation out of `_NFC_SHARED_BYPASS_SPOOL_CHANGED` and into the Python shared-reader path next to the matching `nfc_reader.log` entry. The macro now only calls Moonraker's `spoolman_set_active_spool`.

---

## [0.9.24] - 05/27/2026 - WoodWorker

### Shared Reader LED Target Guard

- Fixed shared-reader legacy LED gate targeting so an MCU-derived index outside Happy Hare's configured gate range no longer sends `MMU_SET_LED GATE=<invalid>`. NFC now falls back to whole-unit LED control for that effect, preventing HH errors such as `The value '4' is not valid for GATE`.
- Documented the fallback in `nfc_reader_shared.cfg` and the shared-reader design notes.
- Added stronger shared-reader hook diagnostics. `NFC_DOCTOR`, startup warnings, and shared pending timeouts now call out when `mmu_macro_vars.cfg` is still wired to the per-lane `NFC JOG_SCAN=1` hook instead of `_NFC_SHARED_PRELOAD`.
- Updated shared-reader docs and config comments so the Happy Hare hook is consistently documented as `variable_user_post_preload_extension: '_NFC_SHARED_PRELOAD'`.
- Restored the shared pending-spool 80% warning as an explicit Klipper console message while keeping the matching entry in `nfc_reader.log`.
- Made the shared 80% pending warning fire from the main poll timer as well as the warning timer, and changed the warning LED effect to avoid HH `DURATION` blocking. `_NFC_SHARED_PRELOAD` now releases warning LED feedback as soon as preload validation begins.

---

## [0.9.23] - 05/26/2026 - WoodWorker

### Shared Reader LED Duration Contract

- Changed normal shared-reader read and staged-ready LED feedback so NFC calls `MMU_SET_LED UNIT=0 EXIT_EFFECT=<effect>` without `DURATION`. These effects must remain interruptible by the next shared-reader state, such as ready, unresolved, warning, loaded, cancel, replace, or timeout.
- Added a local shared-read LED failsafe. If a normal shared read effect starts and no follow-up state takes LED ownership, NFC releases back to Happy Hare with `MMU_GATE_MAP QUIET=1` after `read_effect_duration`.
- Added HH-control restoration on shared read timeout, manual `NFC_SHARED READ=0`, reader failure, disconnect, and print-start polling suspension when no spool is pending.
- Added `NFC_SHARED RESET=1` as a recovery command that clears pending/read/preload shared state, restores HH LED ownership, and restarts shared polling.
- Kept HH `DURATION` only for standalone shared LED feedback: `NFC_SHARED LED_TEST=1`, unresolved feedback, and bypass-ready confirmation. Pending-warning feedback is interruptible so Happy Hare can take LEDs back when preload starts.
- Documented the Happy Hare `MMU_SET_LED DURATION=` behavior: when `DURATION` is passed, HH sets `pending_update[unit] = True`; while that timer is active, later LED effect requests for the same unit are ignored by `_set_led()`.
- Removed stale `ready_effect_duration` documentation for the normal staged-ready path. Staged-ready feedback now follows the shared-reader lifecycle and releases with `MMU_GATE_MAP QUIET=1` on preload commit, cancel, replace, or pending timeout.
- Updated shared-reader tests to assert the interruptible versus timeout-bound LED behavior.

### Repo Hygiene

- Stopped tracking `.claude/settings.json` and added it to `.gitignore` so local agent/editor settings do not appear in repo changes.

---

## [0.9.22] - 05/24/2026 - WoodWorker

### Spoolman UID Registration

- Added `NFC_Register UID=<uid> Spool_id=<id>` so a known NFC UID can be assigned to an existing Spoolman spool directly from the printer console.
- The command validates Spoolman availability, confirms the target spool exists, writes the configured `spoolman_rfid_key`, and clears NFC's UID lookup cache. It intentionally does not call `MMU_SPOOLMAN REFRESH` inline because that Happy Hare path can block Klipper after the Spoolman write succeeds.
- Avoided the full duplicate-UID scan from the Klipper command path so `NFC_REGISTER` stays light.
- Stopped reading the Spoolman PATCH response body after UID registration. Spoolman applies the RFID field update before the body is needed, and waiting for a slow/kept-open body can freeze Klipper's reactor after the UID has already been saved.
- Added command help, README, message documentation, and regression coverage for successful registration and missing-spool rejection.
- Fixed `NFC_REGISTER` help/error rendering so the command appears with the same uppercase styling as other commands, avoids console-swallowed angle-bracket placeholders, and emits command errors once while still writing them to `nfc_reader.log`.

### Lane LED Test Commands

- Added `NFC GATE=<n> LED_TEST=1` to test the configured per-lane tag-read effect on one gate.
- Added `NFC_LED_TEST ALL=1` to test the configured per-lane tag-read effect on every enabled lane reader, with a default 0.20 s chase delay between gates.
- Added `LED_effect_mgr.py` as the NFC/Happy Hare LED contract boundary. Lane scan-jog, shared-reader feedback, and LED test commands now route LED effect naming, public `MMU_SET_LED` effect calls, and HH release requests through the shared manager.
- Completed the LED contract layer with semantic event helpers (`scan_start`, `tag_read`, `rewind`, `spool_ready`, `unresolved`, `auto_create`, `warning`, and `led_test`) and moved lane LED test cycle scheduling into `LED_effect_mgr.py`.
- Fixed `NFC GATE=<n> LED_TEST=1` so the lane LED test dispatches through Klipper's async callback path instead of running nested GCode from inside the command handler.
- Added `CYCLES=<count>` to per-gate and all-lane LED tests. The default is `2`, and each cycle starts the configured base effect with `MMU_SET_LED GATE=<n> EXIT_EFFECT=<effect>`; NFC no longer sends a default-effect restore between cycles and ends the sequence with `MMU_GATE_MAP QUIET=1`.
- Updated command help, README, message docs, and tests for the new LED test commands.

---

## [0.9.21] - 05/23/2026 - WoodWorker

### Scan-Jog LED Reliability

- Added `_NFC_SCAN_JOG_PRELOAD`, a per-lane Happy Hare post-preload hook macro that starts `mmu_clockwise_slow_exit_<gate>` immediately before launching `NFC GATE=<gate> JOG_SCAN=1`.
- Added a delayed scan LED reassert timer so the per-gate clockwise search effect is reapplied after Happy Hare's own LED refreshes from `MMU_GATE_MAP`, `MMU_SELECT`, and `MMU_TEST_MOVE`.
- Reasserted the searching effect after scan prep, each scan step, each jog move, and decode-retry moves so the NFC scan state keeps visible control of the active gate while scan-jog is running.
- Cancelled pending LED reassert timers when scan-jog exits, rewinds, disconnects, or intentionally hands LED control back to Happy Hare.
- Added a short visible tag-read hold before rewind so `mmu_RFID_read_exit_N` can play before the rewind effect starts.
- Kept rewind LED feedback active through the rewind move and released back to Happy Hare only after parking/polling cleanup completes.
- Updated per-lane hook documentation to wire `variable_user_post_preload_extension: '_NFC_SCAN_JOG_PRELOAD'` instead of calling `NFC JOG_SCAN=1` directly.
- Added regression coverage for the hook wrapper ordering, delayed search-effect reassert, and updated scan-jog timing expectations around the tag-read hold.

### Config Defaults

- Fixed default inheritance for the per-lane LED effect names so base `[nfc_gate]` values are available to lane instances unless explicitly overridden.

### Installer

- Stopped installing `nfc_reader_shared.cfg` during lane-reader installs. Shared-reader config is now written only when the user selects the shared-reader install path.
- Reader-type detection now defaults to `shared` only when `printer.cfg` actively includes a shared-reader config, or when a shared-reader config exists without a lane hardware config. Old shared-reader template files no longer force a lane reinstall to default to shared.
- Made interactive choice highlighting consistent: the default selection is highlighted in both the description text and bracket prompt; non-default choices remain unhighlighted.

---

## [0.9.20] - 05/23/2026 - WoodWorker

### Per-Gate LED Feedback — Scan-Jog and Spool Resolution

Added per-gate LED effects for per-lane readers across three events. All effects target only the active gate using HH's `_exit_N` naming convention (`_MMU_SET_LED_EFFECT EFFECT={name}_exit_{gate} REPLACE=1`).

**Scan-jog state machine** (`scan_jog.py`):

| Phase | Effect fired |
|---|---|
| Searching (first scan step, deferred from `start()`) | `mmu_clockwise_slow_exit_N` |
| Tag read confirmed | `mmu_RFID_read_exit_N` |
| Rewind started (tag found or no-tag abort) | `mmu_anticlock_fast_exit_N` |
| Park complete / polling resumed | `MMU_GATE_MAP QUIET=1` → returns LED control to Happy Hare |

**Spool resolution** (`tag_handler.py`):

| Event | Effect fired |
|---|---|
| Spoolman auto-create in progress | `mmu_RFID_creating_exit_N` (stopped when API call returns) |
| Tag found but cannot be resolved to a spool | `mmu_RFID_unresolved_exit_N` (self-terminates) |

- The shared reader already handled `mmu_RFID_creating` and `mmu_RFID_unresolved` via its own effect scheduler. Per-lane effects now use the same `tag_handler.py` call sites, guarded by `not getattr(gate, '_shared', False)`.
- Effect names are configurable in `nfc_reader.cfg` via five new keys in the base `[nfc_gate]` section: `scan_searching_effect`, `scan_tag_read_effect`, `scan_rewind_effect`, `lane_auto_create_effect`, `lane_unresolved_effect`. Per-lane sections inherit these from the base or can override individually. Set any key to empty to disable that effect.
- Module constants `LED_SEARCHING`, `LED_TAG_READ`, `LED_REWINDING` in `scan_jog.py` and `LED_AUTO_CREATING`, `LED_UNRESOLVED` in `tag_handler.py` serve as code-level fallbacks only; the live effect name is always read from `gate._xxx_effect` at runtime.
- The searching effect is deferred to the first reactor timer step (`run_pending_hh_prep`) so it fires from timer context where `gcode.run_script()` is safe.
- Required: all five base effects must be defined with `define_on: gates` (or `define_on: gates, exit`) in the HH LED config so Klipper generates per-gate `_exit_N` variants automatically. `mmu_RFID_read`, `mmu_RFID_creating`, and `mmu_RFID_unresolved` are already defined this way in `nfc_macros.cfg`.

---

## [0.9.19] - 05/22/2026 - WoodWorker

### Reader Diagnostics

- Added `NFC_DOCTOR`, a no-motion setup check that reports configured lane readers, the shared reader, disabled readers, Spoolman availability, shared-reader Happy Hare hook wiring, and static configuration warnings.
- Added startup warnings for configuration combinations that are accepted by Klipper but unlikely to work as intended, including rich-tag reads with tag parsing disabled, auto-create with tag parsing disabled, and auto-create without a usable Spoolman URL.

### Config Compatibility

- Added `enabled: False` support for per-lane and shared `[nfc_gate ...]` sections. Disabled readers keep their config block in place but skip PN532/I2C initialization, command registration, polling, and scan setup while still appearing in status and doctor output.
- Updated the hardware and shared-reader config templates, installer-generated configs, and configuration docs to show the new `enabled` option.

### Documentation and Tests

- Added `NFC_DOCTOR` to the README command list and the Klipper command reference.
- Added regression coverage for doctor command registration, disabled-lane reporting, and static warning generation. Full test suite passes with `376` tests.

---

## [0.9.18] - 05/20/2026 - WoodWorker

### Test Suite — Macro Tests Updated

- Rewrote 4 tests across `test_nfc_macros_config.py` and `test_shared_reader.py` that were asserting old `_NFC_SHARED_PRELOAD` behavior (`MMU_SELECT`, `MMU_GATE_MAP`, `MMU_SPOOLMAN`, `auto_created`). Tests now verify the validate-and-commit-only pattern and assert that gate map calls are absent from the macro.

### Documentation — Config Inheritance Clarified

- Added a `docs/shared/configuration.md` example showing top-level `[nfc_gate]` defaults and per-lane `[nfc_gate laneN]` overrides for values like `i2c_address`, `i2c_bus`, and `scan_enabled`.
- Removed obsolete LED holder files from `NFC Mounting Bracket`, preserving only `LED_holder_with_NFC_Bambu_height v3.step`.

---

## [0.9.17] - 05/20/2026 - WoodWorker

### Shared Preload Macro — Root Cause Fix

- Removed all `MMU_GATE_MAP`, `MMU_SELECT`, and `MMU_SPOOLMAN` calls from `_NFC_SHARED_PRELOAD`. Python stages `MMU_GATE_MAP NEXT_SPOOLID` at tag-read time; Happy Hare processes it during the pregate load and owns the gate map entry by the time `user_post_preload_extension` fires. The macro re-assigning the gate map inside the hook was interfering with HH's finalized state, causing Spoolman ID to remain `-1` in the gate editor even though filament metadata was correct. The macro is now validate-and-commit only: `NFC_SHARED PRELOAD_CHECK=1` and `NFC_SHARED PRELOAD_COMMIT=1`.
- Removed `MMU_SELECT GATE={target_gate}` — HH has already selected the gate before the post-preload hook fires; re-selecting inside the hook can reset gate state and halt macro execution before `PRELOAD_CHECK` runs.

### Shared Preload Macro Cleanup (earlier in session)

- Removed the `auto_created` guard and redundant `MMU_SPOOLMAN REFRESH=1 QUIET=1` — Python already issues the refresh at tag-resolution time before staging `NEXT_SPOOLID`.
- Replaced `MMU_SPOOLMAN SPOOLID={spool_id} GATE={target_gate} QUIET=1` with `MMU_SPOOLMAN SYNC=1 QUIET=1` to match the pattern used by `_NFC_SPOOL_CHANGED`.

### Documentation — First-Install Gaps Fixed

- Added "Shared Reader — Additional Required Steps" section to `install-uninstall.md` covering the two things that silently break a first-time shared-reader install: wiring `variable_user_post_preload_extension: '_NFC_SHARED_PRELOAD'` in `mmu_macro_vars.cfg`, and setting `pending_spool_id_timeout` in `mmu_parameters.cfg` (the 30 s fallback is too short for normal use).
- Fixed stale description in `shared-reader.md` ("What it does" and step 5 of the load flow) that still described the old macro behaviour — selecting the gate and issuing `MMU_GATE_MAP`/`MMU_SPOOLMAN` directly. Both now accurately describe the validate-and-commit-only macro.

---

## [05/20/2026] - WoodWorker

### Shared Reader LEDs

- Changed shared-reader ready, bypass-ready, and warning LED defaults from strobes to breathing-style effects so staged/ready feedback is calmer while the EMU waits.
- Updated `_NFC_SHARED_PRELOAD` to follow the per-lane assignment pattern more closely: select the hook gate, validate/commit the pending spool, apply the local Happy Hare gate map, and directly set the Spoolman gate assignment with `MMU_SPOOLMAN SPOOLID=<n> GATE=<n> QUIET=1`.
- Shared preload now mirrors the per-lane auto-created spool path by running `MMU_SPOOLMAN REFRESH=1 QUIET=1` only when the pending shared-reader spool was newly created, before applying the gate map assignment.
- Removed the obsolete duplicated shared-reader "already assigned" macro branch and the broad gate-map refresh from the shared preload success path.
- `_NFC_SHARED_PRELOAD` now prefers Happy Hare's hook-provided `GATE=<n>` and selects that gate before preload validation, preventing a previously selected lane from receiving the shared reader's resolved spool.
- Fixed bypass unresolved-tag feedback replaying across the shared reader's missed-resolution retries. The unresolved red LED effect now starts only once for an unresolved tag sequence, so bypass mode no longer appears to flash 6 times from three repeated attempts.
- Changed `mmu_RFID_unresolved` to exactly 2 red flashes (`strobe 2 2`) and updated shared-reader config comments, installer text, and docs to match.
- Kept bypass-ready confirmation bounded at 2 seconds and ensured scheduled LED timers stop the exact effect that was started.
- Added configurable shared-reader LED stop durations (`read_effect_duration`, `bypass_read_effect_duration`, `ready_effect_duration`, `bypass_ready_effect_duration`, and `unresolved_effect_duration`) next to their related effect names in `nfc_reader_shared.cfg`.
- Expanded `nfc_reader.cfg` scan-jog comments to document polling lane readers, `NFC JOG_SCAN=1` hook-triggered lane readers, shared-reader preload mode, and the hybrid lane-reader plus shared-reader bypass setup.
- Updated scan-jog's `_NFC_GATE_CLEAR_CACHE` preflight to call `MMU_SPOOLMAN GATE=<n> QUIET=1` before clearing the local HH gate spool ID, so stale Spoolman edit-dialog gate/location assignments are removed before NFC applies the newly read spool.

### Tests

- Added regression coverage proving repeated unresolved shared-reader events only start the red unresolved LED effect once.
- Added regression coverage for custom shared-reader LED effect durations.
- Added static coverage for the scan-jog preflight Spoolman gate unset.

---

## [0.9.15] - 05/19/2026 - WoodWorker

### Pending Spool Timeout Now Sourced from Happy Hare

- Removed `shared_pending_timeout` as a configurable key in `[nfc_gate shared]`. The pending window is now read automatically from Happy Hare's `mmu_parameters.cfg` (`[mmu] → pending_spool_id_timeout`) at Klipper connect time via the Klipper `configfile` object. Falls back to 30 s if the value cannot be read.
- `nfc_reader_shared.cfg` and the installer-generated shared config now carry a comment directing users to set `pending_spool_id_timeout` in `mmu_parameters.cfg` instead of a local override.
- Documentation updated across `docs/shared/configuration.md`, `docs/shared/shared-reader.md`, `docs/shared/klipper-functions.md`, and the design docs to reference the HH parameter.

---

## [05/19/2026] - WoodWorker

### Shared Reader Preload — Spool ID Timing Fix

- `MMU_GATE_MAP NEXT_SPOOLID` is now staged in Python immediately when the NFC tag resolves to a spool, rather than inside the `_NFC_SHARED_PRELOAD` GCode macro. Previously the macro ran AFTER Happy Hare had already finalized the gate map entry for the loaded gate, so the spool ID was never applied to the active gate and it displayed `Id: n/a`.
- For auto-created spools, `MMU_SPOOLMAN REFRESH=1` is also dispatched at resolution time (before `NEXT_SPOOLID`) so Happy Hare knows about the new spool before the hint is staged.
- Removed the now-redundant `MMU_GATE_MAP NEXT_SPOOLID` and `MMU_SPOOLMAN REFRESH` lines from `_NFC_SHARED_PRELOAD`; the macro now only handles validation (`PRELOAD_CHECK`) and commit (`PRELOAD_COMMIT`).
- If Happy Hare already shows the staged shared-reader spool assigned to a loaded gate, `_NFC_SHARED_PRELOAD` now treats that as success and commits the pending NFC read without clearing the Happy Hare gate map. This fixes same-lane eject/read/reinsert flows where the spool briefly loaded and then gate 4 was reset to `Empty` / `Id: n/a`.
- When no spool is pending at preload time (either nothing was tapped or the UID was unresolved), `_NFC_SHARED_PRELOAD` now clears the target gate's map to `SPOOLID=-1 COLOR=FFFFFF55` before firing the `force_spool_id` advisory. Previously the gate retained the previous spool's color and ID so the EMU showed the wrong spool instead of the shadowed unknown state.

### LED Effects

- `mmu_RFID_read` changed from 3 flashes to 1 flash on tag scan, differentiating it clearly from `mmu_RFID_bypass_ready` (3 flashes = bypass spool confirmed).
- Bypass-ready/shared-ready LED effects are now scheduled to stop after 4 seconds when used for immediate bypass spool confirmation, so the confirmation flash does not run indefinitely.
- The shared-reader 80% pending-timeout warning now defaults to `mmu_RFID_warning`, switches from the ready LED to the warning LED at the warning point, and re-arms itself for the actual timeout so expiry cleanup cannot be missed.
- When a shared-reader pending spool expires, NFC now stops the warning LED, issues `MMU_GATE_MAP QUIET=1` to restore Happy Hare steady-state LEDs, and restarts shared polling so another spool can be scanned immediately.

### Shared Reader Installer

- Shared-reader installs no longer inject `shared_led_segment` into generated config; users can own that setting directly in `nfc_reader_shared.cfg`.
- Re-running the installer in shared-reader mode now skips `nfc_reader_hw.cfg` lane-section merging so pure shared installs do not unexpectedly append lane sections.
- Shared-reader installs now update only the selected hardware/startup keys in `[nfc_gate shared]`, preserving user-edited LED settings and comments.
- The installer no longer regenerates the full shared-reader config on every shared install. It now uses targeted `set_config_value` updates for `i2c_mcu`, `i2c_bus`, `shared`, and `startup_polling`.
- Added `detect_mmu_led_unit()` to the installer. It reads `[mmu_leds <name>]` from `mmu_hardware.cfg` and exposes the real unit name so the post-install summary shows the correct whole-chain effect name (e.g., `unit0_mmu_RFID_read_exit`) instead of a hardcoded placeholder.

### Shared Reader LEDs

- `shared_led_segment: exit` keeps the whole-segment LED behavior (`unit0_mmu_RFID_read_exit`).
- `shared_led_segment: gate` restores the legacy single-lane LED behavior (`mmu_RFID_read_exit_N`).
- `shared_led_segment` is normalized to lowercase at load time, so values like `Gate` and `EXIT` resolve consistently.
- `nfc_reader_shared.cfg` now documents `shared_led_segment` as an LED target selector: `exit`/`entry`/`status` target a whole segment, while `gate` targets the legacy single lane.

### Happy Hare Bypass

- Shared-reader spool resolution now detects Happy Hare bypass mode (`printer.mmu.tool == -2`) and immediately sets Moonraker's active Spoolman spool through `_NFC_SHARED_BYPASS_SPOOL_CHANGED`.
- When bypass is active, the shared reader does not stage `NEXT_SPOOLID` or wait for the Happy Hare preload hook; normal shared preload behavior is unchanged for MMU gates.

### Config Compatibility

- Replaced raw CSS hex colors in `_NFC_SPOOL_CHANGED` console messages with named colors so Klipper's config/template parser does not treat `#` as a comment marker and halt during startup.
- Unknown/no-spool NFC metadata now uses `COLOR=FFFFFF55` consistently, matching the scan-unresolved placeholder color.
- Shared-reader preload transaction warnings now use the standard NFC console color tags instead of raising Klipper command errors, avoiding red `!! Error running _NFC_SHARED_PRELOAD` wrappers for nonfatal bridge warnings.
- NFC logger console output now avoids Klipper `RESPOND TYPE=error` / `TYPE=command` coloring and uses the NFC HTML tag colors for `[OK]`, `[WARN]`, and `[ERROR]` consistently.

### Log Rotation and Pruning

- Fixed archive accumulation: `_prune_old_archives` now runs at every Klipper startup, not only when the midnight-crossing `_rotate` path fires. Previously, Klipper restarts before midnight would rename the old log file but never prune, so archives built up indefinitely.
- Retention remains 7 days / 7 archives; the bug was the pruning never ran, not the threshold.

### Console Output and Logging Consistency

- All log message prefixes standardized to `NFC[name]: ` across every module (`nfc_manager.py`, `shared_preload.py`, `tag_handler.py`, `scan_jog.py`). Previously the format varied between `nfc_gate: [name] `, `nfc_gate: `, and bare messages — making it hard to filter logs for a specific gate.
- Switched logger console dispatch away from generated `RESPOND` scripts and onto direct `gcode.respond_info()` calls. This prevents Fluidd/Mainsail from showing `echo:` or Klipper-added prefixes on NFC status lines, while still allowing the NFC logger to color `[OK]`, `[WARN]`, and `[ERROR]` consistently.
- Shared-reader pending warnings and timeout messages now use the same themed prefix format as the rest of the console output: `[WARN] NFC[shared]: ...` and `[ERROR] NFC[shared]: ...`. This fixes the old `NFC [WARN] [shared]` ordering and removes leftover white `[shared]` lane styling.
- Scan-jog and per-lane command replies now use the same themed `NFC[lane]: ...` console prefix, including READ/POLL replies and rewind messages. Logger console output also normalizes older internal `[lane]: ...` messages before they reach the UI.
- `shared_preload.py` fully converted from `gcmd.respond_info()` to `logger.info/warning/error()`. All `PRELOAD_CHECK`, `PRELOAD_COMMIT`, and `PRELOAD_CLEAR_ASSIGNED` feedback now routes through the shared logger so the three output destinations (nfc_reader.log, klippy.log forwarding, and Klipper console) are always in sync.

### Tests

- Added regression coverage for shared LED target naming, including whole-segment and legacy single-gate modes.
- Added regression coverage for shared-reader bypass detection and immediate active-spool assignment.
- Added installer checks to keep `shared_led_segment` out of generated shared config and prevent shared-only installs from merging lane hardware sections.
- Added a macro config guard so `action_respond_info` lines do not use raw CSS hex color literals.
- Added logger regression coverage for direct console dispatch, NFC-themed warning ordering, green `[OK]`, yellow `[WARN]`, red `[ERROR]`, and removal of the old white lane-name styling.
- Added regression coverage for scan-jog rewind and per-lane READ/POLL console prefixes.

---

## [05/18/2026]

### Shared Reader Improvements

- Added full shared-reader command coverage through `NFC_SHARED`, including help, status, summary, cancel, replace, LED test, cache sync, polling, scan, and raw poll actions.
- `NFC_SHARED HELP=1` now documents the required `=1` action flag style so commands match Klipper's parser and avoid malformed bare commands.
- Shared-reader installs now include the base `nfc_reader.cfg` along with `nfc_reader_shared.cfg`, so the standard NFC commands and shared commands are both available after install.
- Shared-reader polling uses the scan-jog reader interval, not the slower base polling interval. The config comments now call this out so tuning the shared reader is less mysterious.
- The shared reader now prints a green `[OK]` line as soon as a tag is successfully read and staged, before the later Happy Hare preload messages.
- `nfc_reader_shared.cfg` now defaults `i2c_mcu: mmu` so the most common wiring works without editing the hardware config.

### LED Behavior

- Shared reader events now flash **all MMU gate exit LEDs simultaneously** instead of a single per-gate LED. All five `mmu_RFID_*` effects now use `define_on: gates, exit`, which creates both per-gate effects (used by per-lane readers) and a whole-chain effect that targets every gate at once (used by the shared reader).
- Fixed indefinitely looping unresolved-tag strobe — it now plays a fixed number of flashes and stops cleanly.
- `mmu_RFID_ready` (green strobe) now persists continuously while a spool is staged and waiting to load; previously it blinked twice and stopped.
- Added `mmu_RFID_warning` amber strobe: plays when the pending timeout is 80% elapsed, giving the user a visible countdown before the spool is dropped.
- Amber warning strobe stops exactly when the pending timeout expires — no overshoot.
- After all NFC effects finish, HH gate LEDs are restored via `MMU_GATE_MAP QUIET=1` only when no spool is pending, preventing HH's gate repaint from killing the active ready effect mid-wait.
- On pending timeout, polling always restarts automatically (equivalent to issuing `NFC_SHARED REPLACE=1`).

### Klipper Deadlock Fix

- Eliminated a class of Klipper deadlocks caused by calling `run_script()` from inside GCode command handlers. All LED, respond, and HH gate-map calls that originate from GCode handlers are now deferred via `register_async_callback`. Affected commands: `NFC_SHARED LED_TEST`, `REPLACE`, `CANCEL`, `CLEAR`, `PRELOAD_CLEAR_ASSIGNED`.

### Happy Hare Preload Behavior

- Fixed the pure shared-reader stale assignment path. If Happy Hare still has a spool assigned to a gate when the shared reader stages that same spool, NFC now clears the stale Happy Hare gate assignment and gets ready for the next tag.
- Hybrid installs are still protected: when per-lane readers are present, the shared reader does not overwrite or clear legitimate per-lane assignments.
- `NFC_SHARED PRELOAD_CLEAR_ASSIGNED=1` now receives the assigned gate number so the automatic cleanup can target the correct Happy Hare gate.
- `force_spool_id` no longer throws a Klipper command error when no spool is staged. It now shows one red `[ERROR]` console advisory instead of duplicated `!!` error lines.
- `_NFC_SHARED_PRELOAD` macro cross-checks `gate_status` when evaluating already-assigned spools — a gate with status 0 (filament absent) is no longer treated as occupied, fixing the case where a spool ejected from a gate with no per-lane reader left a stale HH assignment that blocked future loads of the same spool.

### Console Output

- All NFC console messages now route through the logger rather than inline `RESPOND` GCode calls, eliminating `echo:` format output and removing a second source of deadlocks.
- Standardized console tag colors:
  - `[OK]` renders green.
  - `[WARN]` renders yellow.
  - `[ERROR]` renders red text without forcing a Klipper error unless the command truly fails.
- Reduced duplicate shared-reader warnings by keeping recovered stale-assignment details in the internal log and showing only one concise console warning.
- Replaced stop-sign precondition glyphs with `[ERROR]` for clearer, consistent console messages.

### Documentation

- README and quick-install guide updated with the correct Happy Hare hook parameter: `variable_user_post_preload_extension: '_NFC_SHARED_PRELOAD'` in `mmu_macro_vars.cfg`.
- Install instructions now list the required config includes for shared-reader installs.
- Command reference updated to cover `NFC_SHARED` commands users are expected to run day-to-day.

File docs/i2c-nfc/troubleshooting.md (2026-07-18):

# Troubleshooting

[← README](../../Readme.md) | [Setup](setup.md) | [Expert Debug →](../shared/expert-low-level-i2c-debugging.md)

---

## Quick Links

- [Start Here: MCU Firmware](#start-here-mcu-firmware)
- [Klipper Won't Start - Config Errors](#klipper-wont-start--config-errors)
- [PN532 Not Responding](#pn532-not-responding)
- [PN7160 Not Responding](#pn7160-not-responding)
  - [`connect_nci failed: I2C label=CORE_RESET status=START_NACK`](#connect_nci-failed-i2c-labelcore_reset-statusstart_nack)
  - [`Unable to obtain 'i2c_read_response' response`](#unable-to-obtain-i2c_read_response-response)
- [PN5180 Not Responding](#pn5180-not-responding)
- [BME280 Fails After PN532 Is Added](#bme280-fails-after-pn532-is-added)
- [Tag Detected But No Spool Found](#tag-detected-but-no-spool-found)
- [False Spool Removals](#false-spool-removals)
- [Happy Hare Not Updating](#happy-hare-not-updating)
- [Diagnostic Command Summary](#diagnostic-command-summary)

---

## Start Here: MCU Firmware

> [!CAUTION]
> **The most common source of NFC reader failures is stale lane MCU firmware.**
>
> If you updated the Klipper host but didn't rebuild and flash the EBB42 firmware, the MCU and host are running different protocol versions. I2C failures from this look exactly like hardware problems — bad wiring, wrong mode, broken module.
>
> **Rebuild and flash every lane MCU. Then try again.**

---

## Klipper Won't Start — Config Errors

### `Unknown config section 'nfc_gate'`

The NFC Python module didn't load. Check that the symlinks exist:

```bash
ls -la ~/klipper/klippy/extras/nfc_gate.py
ls -la ~/klipper/klippy/extras/nfc_gates/
```

If missing, run the installer again:
```bash
cd ~/rfid-reader && bash install.sh
```

---

### `Section 'nfc_gate lane0' defined before 'nfc_gate' base section`

The includes in `printer.cfg` are in the wrong order. It must be:

```ini
[include nfc/nfc_reader.cfg]     ← first
[include nfc/nfc_macros.cfg]
[include nfc/nfc_reader_hw.cfg]    ← last
```

---

### `Option 'i2c_mcu' in section 'nfc_gate lane0' is not a valid config option`

Same cause as above — the base `[nfc_gate]` section wasn't loaded before the lane section. Fix the include order.

---

## PN532 Not Responding

### `PN532 did not respond`

The reader isn't answering on the I2C bus at all.

Check in this order:

1. **I2C mode** — SEL0=1, SEL1=0 on the PN532 DIP switches. This is the most common mistake.
2. **Voltage** — VCC is 3.3V (or 5V through onboard regulator if your board supports it, but SDA/SCL must be 3.3V)
3. **GND** — shared between PN532 and lane MCU
4. **SDA/SCL not swapped** — PB3=SCL, PB4=SDA on the EBB42
5. **`i2c_mcu` name** — matches exactly what Klipper uses (e.g. `lane0`, not `mcu_lane0`)
6. **`i2c_address`** — is `36` (hex `0x24`) unless you changed the address pads
7. **MCU firmware** — rebuilt and flashed to match the host Klipper version

Then try:
```gcode
NFC GATE=0 INIT=1
```

Still failing? Go to [Expert: Low-Level I2C Debugging](../shared/expert-low-level-i2c-debugging.md).

---

## PN7160 Not Responding

PN7160 startup problems are usually address, bus, or reset related.

### `connect_nci failed: I2C label=CORE_RESET status=START_NACK`

The MCU could not start an I2C transaction with the PN7160 while sending the
NCI `CORE_RESET` command. In practice this means the PN7160 did not answer on
the configured I2C bus.

Common causes:

- SDA/SCL wiring is disconnected, swapped, or on the wrong MCU pins.
- `i2c_mcu`, `i2c_bus`, or `i2c_address` does not match the hardware.
- The PN7160 is not powered, does not share ground with the MCU, or is held in
  reset.
- The PN7160 is stuck after a failed debug run, forced Klipper stop, or bus
  error.

After checking wiring and config, run:

```gcode
NFC GATE=0 INIT=1
```

or for the shared reader:

```gcode
NFC_SHARED INIT=1
```

If wiring and config look correct but the PN7160 still cannot communicate, power
cycle the PN7160 module. This is especially important when `ven_pin` is not
wired, because Klipper cannot hard-reset the chip without removing power.

Check in this order:

1. **`reader_type`** - the lane/shared section must set `reader_type: pn7160`.
2. **`i2c_address`** - must match the hardware address selection and be one of `40`, `41`, `42`, or `43`.
3. **`i2c_mcu` name** - must match an existing Klipper `[mcu ...]` section.
4. **SDA/SCL not swapped** - verify the selected bus pins.
5. **Power and ground** - confirm the module is powered and shares ground with the MCU.
6. **Bus type** - hardware I2C is recommended. Software I2C is supported, but consumes more MCU time.
7. **VEN state** - if `ven_pin` is wired, confirm the pin is correct. If VEN is not wired and the chip appears stuck, power-cycle the module.

Then try:

```gcode
NFC GATE=0 INIT=1
```

or for the shared reader:

```gcode
NFC_SHARED INIT=1
```

If the PN7160 becomes unusually warm after a failed test or forced Klipper stop,
stop testing and power-cycle it. Wiring `ven_pin` gives Klipper a reliable
hardware reset path.

---

### `Unable to obtain 'i2c_read_response' response`

Klipper asked the MCU for an I2C read and got no reply.

Most common causes:

| Cause | Fix |
|---|---|
| Stale MCU firmware | Rebuild and flash |
| PN532 in wrong mode | Check DIP switches (SPI/UART mode accepts wiggled lines but won't produce I2C responses) |
| PN532 not ready yet | Increase `transceive_delay` to `0.500` |
| SDA/SCL swapped | Swap them |
| Another I2C device stuck | Check if BME280 is holding the bus |

**Quick test:** If `INIT=1` succeeds but polling produces this error, the issue is timing. Try:
```ini
[nfc_gate]
transceive_delay: 0.500
```

If `INIT=1` fails immediately, the bus is not functional — check wiring and mode selection first.

---

## PN5180 Not Responding

PN5180 failures are usually power, SPI wiring, BUSY, or RST related. The
documented SLB connection uses nine wires: 5V, PSF 3.3V, GND, SCK, MISO, MOSI,
NSS/CS, BUSY, and RST. See [PN5180 wiring](pn5180-wiring.md) for the table.

### `invalid PN5180 health registers`

The reader returned invalid register data during initialization. Check these in
order:

1. **Both power rails** - the module needs 5V and the PSF connector's 3.3V.
2. **Ground** - PN5180 and the SLB/MMU must share GND.
3. **SPI direction** - SCK=`PB13`, MISO=`PB14`, MOSI=`PB15`, and NSS=`PA8` for
   the documented SLB wiring.
4. **Configuration** - `spi_bus: spi2_PB14_PB15_PB13`, `cs_pin: mmu:PA8`, and
   `reader_type: pn5180` must match the physical wiring.
5. **RST** - must be connected to the configured MCU output (`mmu:PC6` in the
   SLB example), not tied permanently high.

### `timeout waiting for PN5180 BUSY low`

The BUSY input stayed high longer than `pn5180_busy_timeout` (default `0.100`).
The driver resets and reinitializes the reader after this condition, but a
repeated timeout is a wiring or power fault, not a normal no-tag result.

1. Confirm PN5180 BUSY is connected to the configured input (`mmu:PB0` in the
   SLB example) and is not inverted.
2. Confirm BUSY is not shorted to 3.3V or 5V.
3. Confirm both power rails and RST are connected.
4. Run `NFC_SHARED INIT=1` for a shared reader or `NFC GATE=<n> INIT=1` for a
   lane reader after correcting the wiring.

Do not use `pn5180_command_delay`; the driver synchronizes each command from
the actual BUSY signal. For a complete wire-by-wire check, use
[PN5180 wiring](pn5180-wiring.md).

---

## BME280 Fails After PN532 Is Added

The BME280 (address `0x76`) and PN532 (address `0x24`) share the PB3/PB4 bus without conflict. If the BME280 worked before and breaks after the PN532 is connected:

| Symptom | Likely cause |
|---|---|
| BME280 fails on Klipper start | PN532 is in SPI or UART mode — it's disrupting the bus |
| BME280 works, fails after first INIT | PN532 power issue — voltage droop pulling SDA/SCL low |
| BME280 intermittent | Excessive pull-up current or marginal wiring |
| BME280 never works with PN532 connected | SDA/SCL short or wrong pin assignment |

**Quick check:** Disconnect the PN532 completely. If the BME280 recovers, the fault is physical — the PN532 is disrupting the bus. Check mode selection first.

---

## Tag Detected But No Spool Found

The hardware is working — the NFC reader read the tag. The Spoolman lookup failed.

```gcode
NFC GATE=0 POLL=1
```

Check:

1. **`spoolman_url`** — visit it in a browser from the Pi: `curl http://yourhost:7912/api/v1/spool`
2. **`spoolman_rfid_key`** — must match the extra field name in Spoolman **exactly** (case-sensitive)
3. **UID is on the spool record**, not the filament record
4. **No typos in the UID** — copy-paste from the console, don't transcribe by hand

Enable verbose logging to see the full HTTP exchange:

```ini
[nfc_gate]
debug:             2
console_output:    True
console_log_level: info
```

Restart Klipper, run `POLL=1`, and read the log.

---

## False Spool Removals

Gate declares the spool removed while it's still physically there.

**Cause:** The reader is occasionally missing reads (tag angle, vibration, RF environment), and `absent_threshold` is too low.

Default settings require 3 consecutive misses (~90s) before removal:
```ini
poll_interval:    30
absent_threshold: 3
```

If you're still getting false removals, raise the threshold:
```ini
absent_threshold: 5    ; ~150s before removal at default interval
```

---

## Happy Hare Not Updating

NFC is detecting tags and looking up spools, but Happy Hare's gate map isn't changing.

**Test the macro directly** — no hardware needed:

```gcode
_NFC_SPOOL_CHANGED GATE=0 SPOOL_ID=42 UID=04AABBCCDD
```

- **If this updates Happy Hare:** the macro is fine. The problem is upstream — a polling or Spoolman issue.
- **If this doesn't update Happy Hare:** check `nfc_macros.cfg` and Happy Hare command compatibility.

Common macro issues:

- Wrong `MMU_GATE_MAP` parameter syntax for your Happy Hare version
- Macro was accidentally deleted or commented out
- Happy Hare is in a state that rejects `MMU_GATE_MAP` (e.g. mid-print with gate locks)
- `spoolman_support: push` is not set in Happy Hare, so `SYNC=1` does nothing

---

## Diagnostic Command Summary

```gcode
NFC_STATUS                    ; all gates — current state
NFC GATE=0 STATUS         ; one gate
NFC GATE=0 INIT=1         ; re-initialize the NFC reader
NFC GATE=0 SCAN=1         ; one raw read, no state machine or Spoolman
NFC GATE=0 POLL=1         ; one complete cycle, watch for console output
```

For deeper investigation, enable expert debug mode:

```ini
[nfc_gate]
low_level_debug:   True
console_output:    True
console_log_level: info
```

Then:
```gcode
NFC GATE=0 HELP      ; lists all available debug commands
```

See [Expert: Low-Level I2C Debugging](../shared/expert-low-level-i2c-debugging.md) for the complete step-by-step manual sequence.

---

*Copyright (C) 2026 WoodWorker. Licensed under [GPL-3.0-or-later](https://www.gnu.org/licenses/gpl-3.0.html) — see [LICENSE](../../LICENSE).*

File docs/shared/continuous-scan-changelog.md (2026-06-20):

# Continuous Scan Changelog

Branch: `CW-Development`

## Added

- Added opt-in `scan_motion_mode: continuous` for scan-jog.
- Added continuous scan config:
  - `scan_continuous_step_mm: 50.0`
  - `scan_continuous_speed: 150.0`
  - `scan_continuous_accel: 2000.0`
  - `scan_continuous_poll_interval: 0.05`
- Added `MMU_TEST_MOVE WAIT=0` forward jog support for continuous scan.
- Added trapezoid timing estimation for continuous scan chunks so the next
  read/check is scheduled after the estimated move completion plus the
  configured check gap.

## Behavior

- Default scan behavior remains `stopped`.
- Continuous scan only changes the forward search jog pacing.
- Happy Hare's default `MMU_TEST_MOVE` motor remains `gear`; continuous scan
  does not need to pass `MOTOR=gear`.
- Tag-found handling still uses the existing scan completion path:
  - stop queueing forward moves
  - preserve the 0.1 second read-light hold
  - rewind using the existing rewind path
  - dispatch the cached tag/spool action after rewind
- Decode retry moves remain on the existing stopped/blocking retry path.

## Motion Profile

With the default continuous values:

- 50 mm move
- 150 mm/s speed
- 2000 mm/s^2 acceleration
- 0.05 s post-move tag-check gap

Estimated motion:

- Accel time: about 0.075 s
- Cruise distance: about 38.75 mm
- Move duration: about 0.408 s
- Effective scan advance including the 0.05 s check gap: about 109 mm/s

## Files Changed

- `klippy/extras/nfc_gates/scan_jog.py`
- `klippy/extras/nfc_gates/nfc_manager.py`
- `config/nfc_reader.cfg`
- `docs/shared/configuration.md`
- `docs/shared/scan-jog-wait0-design-note.md`

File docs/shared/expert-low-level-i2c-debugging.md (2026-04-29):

# Expert: Low-Level PN532 I2C Debugging

[← Back to README](../../Readme.md) | [Troubleshooting](../i2c-pn532/troubleshooting.md)

---

> [!WARNING]
> ## Expert Section — Read This First
>
> The commands in this section send raw bytes directly to the PN532 over I2C. They **bypass the normal state machine** entirely. Sending the wrong sequence or leaving a step half-finished can put the PN532 into a state where normal polling fails until the MCU power cycles or Klipper restarts.
>
> **Use these commands only:**
> - During initial bring-up of a new PN532 reader when normal `INIT=1` fails.
> - When you have exhausted normal troubleshooting and need to observe exactly what the bus is doing.
>
> **Do not leave `low_level_debug: True` enabled during printing.**

---

## Enabling Expert Mode

In `nfc_reader.cfg`:

```ini
[nfc_gate]
low_level_debug:   True
console_output:    True
console_log_level: info
```

Restart Klipper. When `low_level_debug` is enabled, Klipper starts cleanly but **the PN532 is not initialized**. The driver skips the wake sequence and SAMConfiguration entirely so no driver-initiated bus traffic interferes with your manual commands. The log will confirm this:

```
init: gate 0 (PN532) low_level_debug enabled — skipping wake and SAMConfiguration
```

You must run the manual init sequence (Phase 1 + Phase 2 below) before any tag read commands will work. Then ask for the command list:

```gcode
NFC GATE=0 HELP=1
```

This prints the full manual init sequence with the exact commands to paste, in order.

---

## What Expert Mode Exposes

Expert mode ports the bring-up workflow from the original `PN_CONSOLE` diagnostic tool into Klipper GCode. Each `STEP=` command executes one discrete PN532 bus transaction and reports exactly what was sent and what came back, before and after.

### Transparency output format

Every command prints:

```
NFC[lane0]: FIRMWARE WRITE before: 00 00 FF 02 FE D4 02 2A 00
NFC[lane0]: FIRMWARE WRITE after:  OK
NFC[lane0]: NEXT: NFC GATE=0 STEP=FIRMWARE_ACK
```

- **before**: the bytes that are about to be sent.
- **after**: the result (`OK`, the raw bytes read, or an error).
- **NEXT**: the next command to paste when this step succeeded.

This "paste the next command" pattern comes from the original console bring-up flow, where you run one command at a time and observe the result before proceeding.

---

## PN532 I2C Protocol Background

Understanding what you are looking at requires knowing the PN532 frame format.

### Frame structure

**Write frame (host → PN532):**

```
00 00 FF  LEN  LCS  TFI  CMD  [params]  DCS  00
```

**Read frame (PN532 → host):**

```
STATUS  00  00  FF  LEN  LCS  TFI  CMD  [data]  DCS  00
```

| Field | Meaning |
|---|---|
| `STATUS` | First byte of every I2C read. `0x01` = ready, `0x00` = busy (PN532 still processing). |
| `LEN` | Number of bytes in the data field (TFI + CMD + payload). |
| `LCS` | Length checksum: `(-LEN) & 0xFF`. LEN + LCS = 0 mod 256. |
| `TFI` | Transport Frame Identifier. `0xD4` = host→PN532, `0xD5` = PN532→host. |
| `CMD` | Command code. Response code is `CMD + 1`. |
| `DCS` | Data checksum: `(-sum(data_field)) & 0xFF`. |

### ACK frame

After every command write, the PN532 sends an ACK before it processes the command. The ACK frame is:

```
00 00 FF 00 FF 00
```

When read over I2C (including the status byte at the front):

```
01 00 00 FF 00 FF 00
```

The leading `01` is the STATUS byte (ready). The ACK itself is the remaining 6 bytes.

### PN532 command codes

| Command | Code | Purpose |
|---|---|---|
| `GetFirmwareVersion` | `0x02` | Verify PN532 is alive, get firmware version |
| `SAMConfiguration` | `0x14` | Configure Security Access Module (required before tag reads) |
| `InListPassiveTarget` | `0x4A` | Detect ISO14443A tag and return UID |
| `InRelease` | `0x52` | Release/deselect the current target |

---

## Manual Init Sequence

> [!IMPORTANT]
> **Phase 1 and Phase 2 are mandatory.** The PN532 is not initialized when Klipper starts in expert mode. You must complete both phases before tag detection (Phase 3) or any other read commands will work.

Run one command at a time. Wait for the response before running the next. If any step fails, do not proceed — diagnose the failure at that step.

### Phase 1: Wake and firmware check

```gcode
NFC GATE=0 STEP=WAKEUP
NFC GATE=0 STEP=READY
NFC GATE=0 STEP=FIRMWARE_WRITE
NFC GATE=0 STEP=FIRMWARE_ACK
NFC GATE=0 STEP=FIRMWARE_READY
NFC GATE=0 STEP=FIRMWARE_RESPONSE
```

**What each step does:**

| Step | Bus operation | Expected result |
|---|---|---|
| `WAKEUP` | Writes `0x00` to nudge the PN532 transport out of power-down mode | No response needed |
| `READY` | Reads 1 byte | `01` = ready |
| `FIRMWARE_WRITE` | Writes the `GetFirmwareVersion` command frame | `OK` |
| `FIRMWARE_ACK` | Reads 7 bytes | `01 00 00 FF 00 FF 00` |
| `FIRMWARE_READY` | Polls the STATUS byte until `01` | `01` |
| `FIRMWARE_RESPONSE` | Reads the full firmware response | `01 00 00 FF 06 FA D5 03 ...` containing IC, Ver, Rev, Support bytes |

If `FIRMWARE_WRITE` succeeds but `FIRMWARE_ACK` returns wrong bytes or errors, the problem is in the write→ACK round trip: timing, MCU firmware version, or I2C bus quality.

### Phase 2: SAM configuration

```gcode
NFC GATE=0 STEP=SAM_WRITE
NFC GATE=0 STEP=SAM_ACK
NFC GATE=0 STEP=SAM_READY
NFC GATE=0 STEP=SAM_RESPONSE
```

`SAMConfiguration` sets the PN532 to normal mode (no SAM involvement). It must succeed before `InListPassiveTarget` will work.

### Phase 3: Tag detect (optional — requires Phase 1 + 2 complete)

With the PN532 initialized, you can test tag detection:

```gcode
NFC GATE=0 STEP=PASSIVE_WRITE
NFC GATE=0 STEP=PASSIVE_ACK
NFC GATE=0 STEP=PASSIVE_READY
NFC GATE=0 STEP=PASSIVE_RESPONSE LEN=30
```

Hold a tag near the reader before running `PASSIVE_WRITE`. The `PASSIVE_RESPONSE` bytes will contain the UID if a tag was found.

---

## Step Reference

| Step | PN532 operation | What it sends / reads |
|---|---|---|
| `WAKEUP` | Nudge transport | Writes `0x00` |
| `READY` | Read STATUS byte | Reads 1 byte. Expects `01`. |
| `FIRMWARE_WRITE` | `GetFirmwareVersion` command | Writes full PN532 frame for command `0x02` |
| `FIRMWARE_ACK` | Read ACK for firmware command | Reads 7 bytes. Expects `01 00 00 FF 00 FF 00`. |
| `FIRMWARE_READY` | Wait for firmware response readiness | Polls STATUS until `01` |
| `FIRMWARE_RESPONSE` | Read and parse firmware response | Reads full response frame, prints IC/Ver/Rev |
| `SAM_WRITE` | `SAMConfiguration` command | Writes frame for command `0x14` |
| `SAM_ACK` | Read ACK for SAM command | Reads 7 bytes. Expects ACK pattern. |
| `SAM_READY` | Wait for SAM response readiness | Polls STATUS until `01` |
| `SAM_RESPONSE` | Read and parse SAM response | Reads response, confirms success |
| `PASSIVE_WRITE` | `InListPassiveTarget` command | Writes frame for command `0x4A` |
| `PASSIVE_ACK` | Read ACK for passive target command | Reads 7 bytes. Expects ACK pattern. |
| `PASSIVE_READY` | Wait for tag-detect response readiness | Polls STATUS until `01` (waits up to `transceive_delay`) |
| `PASSIVE_RESPONSE` | Read tag-detect response | Reads `LEN` bytes. Contains UID if tag found. |

---

## Direct ACK Timing Probe

`FIRMWARE_ACK_DIRECT` writes `GetFirmwareVersion` and immediately reads the ACK frame with a configurable delay between write and read:

```gcode
NFC GATE=0 STEP=FIRMWARE_ACK_DIRECT DELAY=0.050
```

Use this to find the minimum delay that still produces a valid ACK. Start at 50 ms and increase:

```gcode
NFC GATE=0 STEP=FIRMWARE_ACK_DIRECT DELAY=0.100
NFC GATE=0 STEP=FIRMWARE_ACK_DIRECT DELAY=0.200
```

If you find that ACK reads fail below a certain delay, that is a signal about your bus latency (CAN round-trip + PN532 processing). Increase `transceive_delay` to match.

---

## Raw Tools

These bypass the `STEP=` sequence entirely and give direct bus access.

### `READY_READ` — Read the PN532 status byte

```gcode
NFC GATE=0 READY_READ=1
```

Reads 1 byte from the PN532 I2C address.

| Result | Meaning |
|---|---|
| `01` | PN532 is ready — a response is waiting in its buffer |
| `00` | PN532 is busy — still processing the last command |

Use this to check whether the PN532 is alive and whether a previous command completed.

---

### `ACK_READ` — Read the ACK frame

```gcode
NFC GATE=0 ACK_READ=1 LEN=7
```

First reads the STATUS byte. If STATUS is `01` (ready), reads `LEN` more bytes.

**Expected good ACK:**

```
01 00 00 FF 00 FF 00
```

The `01` is STATUS (ready). The remaining 6 bytes are the PN532 ACK frame. If you see anything else, the PN532 is either not ready, or the previous write did not produce a standard ACK.

---

### `RAW_READ` — Read raw bytes

```gcode
NFC GATE=0 RAW_READ=1 LEN=1
```

Reads exactly `LEN` bytes from the PN532 I2C address without any interpretation. The raw bytes are printed to the console.

---

### `RAW_WRITE` — Write raw bytes

```gcode
NFC GATE=0 RAW_WRITE=00
NFC GATE=0 RAW_WRITE=00,00,FF,02,FE,D4,02,2A,00
```

Writes the specified bytes exactly as given. Accepts space, comma, colon, or dash-separated hex values. No framing is added.

---

### `RAW_CMD` — Write a framed PN532 command

```gcode
NFC GATE=0 RAW_CMD=02
```

Builds and sends a complete PN532 command frame for the given command byte. For command `0x02` (`GetFirmwareVersion`) with no additional parameters, the full frame is:

```
00 00 FF 02 FE D4 02 2A 00
```

The driver calculates `LEN`, `LCS`, `TFI`, `DCS` and the preamble/postamble automatically.

---

## Disabling Expert Mode

When bring-up is complete:

```ini
[nfc_gate]
low_level_debug:   False
console_output:    False
```

Restart Klipper.

Normal polling (`READ=1`) will now function without interference from manual bus commands.

---

*Copyright (C) 2026 WoodWorker. Licensed under [CC BY-NC-SA 4.0](https://creativecommons.org/licenses/by-nc-sa/4.0/) — see [LICENSE](../../LICENSE).*

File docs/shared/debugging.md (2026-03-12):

# Debugging & Log Reference

[← Back to Index](../../Readme.md)

---

## NFC_GATE_STATUS Command

Run from the Klipper console (Mainsail / Fluidd terminal) at any time:

```
NFC_GATE_STATUS
```

**SPI / RC522 output** (one `[nfc_gates]` section, all gates in one command):
```
NFC gate status — 5 gates, poll 30s, absent threshold 3:
  Gate 0: spool 1042    UID A3F200CC
  Gate 1: empty
  Gate 2: spool 207     UID B1D4A209
  Gate 3: empty
  Gate 4: READER FAILED (check wiring)
```

**I2C / PN532 output** (one `[nfc_gate laneN]` section per gate):
```
NFC gate status  (4 gates configured):
  Gate 0  [lane0]:  spool 1042    UID A3F200CC
  Gate 1  [lane1]:  empty
  Gate 2  [lane2]:  spool 207     UID B1D4A209
  Gate 3  [lane3]:  tag A3F200CC  (no spool ID — write one with NFC Tools)
```

This reflects the last poll result — it is not a live read. To force an immediate
read, reduce `poll_interval` to `5` in the config and restart Klipper.

---

## Klipper Log

All NFC events are written to `klippy.log`:

```bash
# Follow live
tail -f ~/printer_data/logs/klippy.log | grep nfc_gate

# Search for gate changes only
grep "state change\|spool.*detected\|spool removed" ~/printer_data/logs/klippy.log

# Show the last 100 NFC lines
grep nfc_gate ~/printer_data/logs/klippy.log | tail -100
```

---

## Debug Verbosity

Set `debug:` in your config section to control log detail.

| Value | Output |
|---|---|
| `0` | Errors and warnings only |
| `1` | Major events: poll cycles, tag detected/removed, state changes **(default)** |
| `2` | Full trace: every register read/write (SPI) or I2C frame (PN532), FIFO contents, CRC values |

**SPI / RC522** — set inside `[nfc_gates]`:
```ini
[nfc_gates]
debug: 2
```

**I2C / PN532** — set inside any or all `[nfc_gate]` sections:
```ini
[nfc_gate lane0]
debug: 2
```

Restart Klipper after changing. Revert to `debug: 1` after debugging (debug=2 is very chatty at a 30 s poll interval with 5 gates).

---

## Expected Log Output at debug: 1

### SPI / RC522 — successful startup and poll cycle

```
nfc_gates: connected to MCU 'nfc_pico', initialising 5 gates (poll=30s, absent_threshold=3, debug=1)
nfc_gates: gate 0 init — soft-resetting RC522
nfc_gates: gate 0 RC522 init OK (TxControl=0x83)
nfc_gates: gate 1 RC522 init OK (TxControl=0x83)
...
nfc_gates: 5/5 readers initialised
nfc_gates: polling thread started
nfc_gates: poll cycle — checking 5 gate(s)
nfc_gates: gate 0 — no tag (miss_count=1)
nfc_gates: gate 0 read_tag — tag detected UID=A3F200CC
nfc_gates: gate 0 — state change: CHANGED (uid=A3F200CC spool=1042)
```

### I2C / PN532 — successful startup

```
nfc_gate: [lane0] connected — gate=0, poll=30s, absent_threshold=3, debug=1
nfc_gate: [lane0] PN532 reader OK
nfc_gate: [lane0] polling thread started
nfc_gate: [lane0] gate 0 — no tag (miss 1)
nfc_gate: [lane0] gate 0 — CHANGED uid=A3F200CC spool=1042
```

---

## Reducing Poll Interval for Testing

Change `poll_interval` and `absent_threshold` for faster feedback during setup.
Do this in the config file and restart Klipper — no hardware changes needed.

```ini
# Fast testing settings — restore to production values when done
poll_interval:    5    # check every 5 seconds instead of 30
absent_threshold: 1    # report removal after first missed poll
```

Production values: `poll_interval: 30` / `absent_threshold: 3`
(3 missed polls = ~90 seconds absence before REMOVED fires — prevents false removals from RF glitches.)

---

## Simulating Events Without Hardware

Use the Klipper console to test your Happy Hare macro integration directly,
without waiting for a physical tag:

```
# Simulate spool placed on gate 0
_NFC_SPOOL_CHANGED GATE=0 SPOOL_ID=1042 UID=A3F200CC

# Simulate spool removed from gate 0
_NFC_SPOOL_REMOVED GATE=0

# Simulate unwritten tag
_NFC_TAG_NO_SPOOL GATE=2 UID=DEADBEEF
```

Verify that `MMU_GATE_MAP` updates correctly in Happy Hare before deploying hardware.

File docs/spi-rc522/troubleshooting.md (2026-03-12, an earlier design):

# SPI / RC522 — Troubleshooting

[← Back to SPI Setup](setup.md) | [← Back to Index](../../Readme.md)

---

## Reader did not respond after init

```
nfc_gates: gate N reader did not respond after init (check wiring)
```

The RC522 could not be reached over SPI. Work through these checks in order:

1. **Power** — verify RC522 VCC is connected to Pico 3V3 OUT, not VBUS (5V).
2. **SPI bus** — confirm SCK=GP10, MOSI=GP11, MISO=GP8 on every reader.
3. **CS wire** — verify the SDA wire for gate N is connected to the correct GPIO (GP0–GP3 for gates 0–3, GP6 for gate 4).
4. **Isolation** — disconnect all but gate 0 and test with a single reader. If gate 0 works alone, add readers one at a time.
5. **Module swap** — if one reader never responds but others do, the module may be faulty.

Enable `debug: 2` in `[nfc_gates]` and restart Klipper to see every SPI register read/write.

---

## Klipper does not connect to nfc_pico

```
mcu 'nfc_pico': Unable to connect
```

- Run `~/klippy-env/bin/python ~/klipper/scripts/canbus_query.py can0` — the Pico must appear.
- If it does not appear, the Pico is not running Klipper MCU firmware or is not on the CAN bus.
- Verify the CAN transceiver is wired correctly (GP4=TX, GP5=RX) and the RS pin is tied to GND.
- Check CAN bus termination (120 Ω at each physical end of the bus).
- Reflash the Pico following [setup.md Steps 2–3](setup.md).
- Verify `canbus_uuid` in `nfc_gates_spi_rc522.cfg` matches the UUID from `canbus_query.py`.

---

## Tags detected intermittently

- **Tag size** — small sticker tags (≤25 mm) have a read range of 3 mm or less. Use 50 mm disc tags.
- **Tag positioning** — the antenna must be within 1–3 cm. Misalignment reduces range to near zero.
- **RF bleed** — RC522 antennas are all powered at once. Adjacent gates within 3 cm of each other can interfere. Increase physical separation or add ferrite backing.
- **False removals** — increase `absent_threshold` from 3 to 5 to require more consecutive misses before reporting removal.

---

## Tag detected but no spool ID (`_NFC_TAG_NO_SPOOL` fires)

The tag is in the RF field and the UID is read, but pages 4–7 contain no parseable spool ID.

- Write the spool ID with NFC Tools app: **Add record → Text** → enter the integer ID (e.g. `1042`). See [tag-writing.md](../shared/tag-writing.md).
- If you used an NDEF URL or SmartPoster record type, overwrite with a plain Text record.
- If the tag was written with binary encoding, it should be caught by the fallback uint32 parser — check klippy.log with `debug: 2` to see the raw bytes read from pages 4–7.

---

## SPI bus errors (ErrorReg collisions or CRC errors)

```
nfc_gates: gate N  _transceive -> MI_ERR (ErrorReg=0x1B: collision=1 CRC=1 ...)
```

- More than one tag in the RF field simultaneously on the same gate — only one tag per gate is supported.
- MISO or MOSI wiring fault causing bus corruption — check for shorts between SPI lines.
- Reduce `spi_speed` from 1000000 to 500000 in `[nfc_gates]` if you have very long jumper wires (>30 cm).

---

## All gates report errors after a Klipper reconnect

When Klipper reconnects after a disconnect/restart, the RC522 readers are re-initialised automatically. If init fails on all gates after a reconnect, the Pico MCU may have lost power or rebooted — check the CAN bus and Pico power supply.

---

## Polling thread stops logging

If log output stops for more than 2× `poll_interval`, the background polling thread has likely raised an unhandled exception. Check klippy.log for:

```
nfc_gates: unexpected error in poll cycle
```

Followed by a Python traceback. Report the traceback as a bug.

---

## debug: 2 log reference

| Log pattern | Meaning |
|---|---|
| `W CommandReg = 0x0F` | Soft-reset sent |
| `R TxControlReg -> 0x83` | Antenna TX pins confirmed active |
| `_transceive -> MI_ERR (timer expired, no tag response)` | No tag in field — normal |
| `_transceive -> MI_OK fifo=5 bits=40` | Tag responded to REQA/ANTICOLL |
| `READ page N OK data=[...]` | 4 bytes of user data read from tag page |
| `spool ID parsed as ASCII decimal: 1042` | Spool ID found — primary strategy |
| `spool ID parsed as big-endian uint32: 1042` | Spool ID found — fallback strategy |

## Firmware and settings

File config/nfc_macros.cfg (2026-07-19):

# =============================================================================
# ============== EMU NFC GATE READER - HAPPY HARE INTEGRATION MACROS ===========
# =============================================================================
# Include this file from printer.cfg alongside the hardware config:
#
#   Per-lane install:
#     [include nfc/nfc_reader.cfg]
#     [include nfc/nfc_macros.cfg]
#     [include nfc/nfc_reader_hw.cfg]
#
#   Shared reader install (single NFC reader inside MMU body):
#     [include nfc/nfc_reader.cfg]
#     [include nfc/nfc_macros.cfg]
#     [include nfc/nfc_reader_shared.cfg]
#
#   Hybrid (per-lane + shared reader):
#     [include nfc/nfc_reader.cfg]
#     [include nfc/nfc_macros.cfg]
#     [include nfc/nfc_reader_hw.cfg]
#     [include nfc/nfc_reader_shared.cfg]
#
# Customise the GCode bodies here to match your Happy Hare version.  Do not put
# Happy Hare calls in NFC reader drivers or SpoolmanClient.
#
#
##################################### DISCLAIMER ########################################

# You, and you alone, are responsible for the correct execution of these macros and 
# gcodes. Any damage that may occur to your machine remains your responsibility. 
# Especially when executing this macro for the first few times, keep an eye on your 
# printer.

##########################################################################################
#
# =============================================================================
# =========================== PER-LANE READER MACROS ===========================
# =============================================================================
# Dispatched by nfc_gates/nfc_gate when a tag is read on a gate reader:
#
#   _NFC_SPOOL_CHANGED : GATE (int)  SPOOL_ID (int)  UID (hex string)  [AUTO_CREATED=1]
#                        [SCAN_FINISH=1] accepted for compatibility
#                        — or when Spoolman is disabled —
#                        GATE (int)  MATERIAL (str, optional)  COLOR (hex str, optional)
#                                    TEMP (int °C, optional)   UID (hex string)
#                                    [SCAN_FINISH=1] accepted for compatibility
#   _NFC_SPOOL_REMOVED : GATE (int)
#   _NFC_TAG_NO_SPOOL  : GATE (int)  UID (hex string)  [SPOOLMAN_DISABLED=1]
#                        [SCAN_FINISH=1] accepted for compatibility
#   _NFC_SCAN_UNRESOLVED : GATE (int)
#
# Integration model:
#   NFC_Manager reads the tag UID, asks SpoolmanClient to resolve it to a spool,
#   then dispatches these macros.  Happy Hare's local gate map is the source of
#   truth.  MMU_GATE_MAP updates the local map; MMU_SPOOLMAN SYNC=1 pushes the
#   spool location to Spoolman ("<hostname> @ MMU Gate:<gate>").
#   _NFC_TAG_NO_SPOOL fires when a tag UID cannot be resolved to a spool.
#
# Wire per-lane scan-jog installs into Happy Hare's mmu_macro_vars.cfg:
#
#   variable_user_post_preload_extension: '_NFC_SCAN_JOG_PRELOAD'
#
#   _NFC_SCAN_JOG_PRELOAD: called by HH's user_post_preload_extension hook
#     after the pregate load. It starts NFC scan-jog on the gate supplied by
#     Happy Hare; NFC starts the configured scan-jog LED effect from Python.
#
# =============================================================================
# ============================= SHARED READER MACRO ============================
# =============================================================================
# Wire this into Happy Hare's mmu_macro_vars.cfg:
#
#   variable_user_post_preload_extension: '_NFC_SHARED_PRELOAD'
#
#   _NFC_SHARED_PRELOAD: called by HH's user_post_preload_extension hook after
#     the pregate load.  Validates and commits the staged spool ID.  Safe to
#     leave wired for all loads — it skips while printing and emits an advisory
#     when no spool is pending.
# =============================================================================

[gcode_macro _NFC_SCAN_JOG_PRELOAD]
description: Called by Happy Hare post-preload hook — starts per-lane NFC scan-jog
# Wire this into Happy Hare's _MMU_SEQUENCE_VARS for per-lane readers:
#   variable_user_post_preload_extension: '_NFC_SCAN_JOG_PRELOAD'
#
# Happy Hare V3 appends GATE=<n>; V4 invokes this hook without parameters, so
# the macro falls back to Happy Hare's current selected gate.
#
# SOURCE=AUTO tells NFC this call comes from Happy Hare's own hook. It permits
# Happy Hare v4's action=checking post-preload state through the version-aware
# scan-safe check. Do not add SOURCE=AUTO to manual/console invocations of
# JOG_SCAN=1.
gcode:
    {% if params.GATE is defined %}
        {% set gate = params.GATE | int %}
    {% else %}
        {% set gate = printer.mmu.gate | default(-1) | int %}
    {% endif %}

    {% set num_gates = printer.mmu.num_gates | default(0) | int %}

    {% if gate < 0 or (num_gates > 0 and gate >= num_gates) %}
        { action_raise_error("NFC post-preload could not determine Happy Hare gate. GATE param missing and printer.mmu.gate=%d" % gate) }
    {% endif %}
    NFC GATE={gate} JOG_SCAN=1 SOURCE=AUTO

[gcode_macro _NFC_SPOOL_CHANGED]
description: Called by nfc_gates/nfc_gate when a spool NFC tag is placed on a gate
gcode:
    {% set gate     = params.GATE | int %}
    {% set reader   = params.READER | default('Lane' ~ gate) %}
    {% set uid      = params.UID | default('') %}
    {% if params.SPOOL_ID is defined %}
        {% set spool_id     = params.SPOOL_ID | int %}
        {% set auto_created = params.AUTO_CREATED | default(0) | int %}
        { action_respond_info('<span style="color:lightgreen">[OK]</span> NFC[%s]: spool %d detected (UID %s)%s. Sending to Happy Hare.' % (reader, spool_id, uid, " [new spool]" if auto_created else "")) }
        {% if auto_created %}
            MMU_SPOOLMAN REFRESH=1 QUIET=1
        {% endif %}
            MMU_GATE_MAP GATE={gate} SPOOLID={spool_id} AVAILABLE=1 SYNC=1 QUIET=1
    {% else %}
        {% set name     = params.NAME     | default('') %}
        {% set material = params.MATERIAL | default('') %}
        {% set color    = params.COLOR    | default('') %}
        {% set brand    = params.BRAND    | default('') %}
        {% set min_temp = params.MIN_TEMP | default('') %}
        {% set temp     = params.TEMP     | default('') %}
        {% set diameter = params.DIAMETER | default('') %}
        {% set weight   = params.WEIGHT   | default('') %}
        { action_respond_info('<span style="color:lightgreen">[OK]</span> NFC[%s]: tag metadata detected (UID %s) — no Spoolman. brand=%s name=%s material=%s color=%s min=%s max=%s dia=%smm weight=%sg' % (reader, uid, brand, name, material, color, min_temp, temp, diameter, weight)) }
        MMU_GATE_MAP GATE={gate}{% if name %} NAME={name}{% endif %}{% if material %} MATERIAL={material}{% endif %}{% if color %} COLOR={color}{% endif %}{% if temp %} TEMP={temp | int}{% endif %} AVAILABLE=1 QUIET=1
    {% endif %}
    MMU_GATE_MAP GATE={gate} APPLY=1 QUIET=1
    MMU_SPOOLMAN SYNC=1 QUIET=1


[gcode_macro _NFC_SPOOL_REMOVED]
description: Called by nfc_gates/nfc_gate when a spool NFC tag is removed from a gate
gcode:
    {% set gate = params.GATE | int %}
    {% set reader = params.READER | default('Lane' ~ gate) %}
    {% set mmu_action = printer.mmu.action | default("") | lower %}
    {% if "load" in mmu_action or "unload" in mmu_action or "homing" in mmu_action %}
        { action_respond_info("NFC[%s]: tag absent during MMU operation (%s) — ignoring removal." % (reader, mmu_action)) }
    {% else %}
        { action_respond_info('NFC[%s]: spool removed. Clearing Happy Hare gate.' % reader) }
        MMU_GATE_MAP GATE={gate} SPOOLID=-1 AVAILABLE=0 SYNC=1 QUIET=1
        MMU_GATE_MAP GATE={gate} APPLY=1 QUIET=1
        MMU_SPOOLMAN SYNC=1 QUIET=1
    {% endif %}


[gcode_macro NFC_HH_SYNC_CACHE]
description: Re-seed NFC lane cache from Happy Hare gate map
# Reads the current Happy Hare gate map and tells each NFC lane about its
# current spool assignment.  On the next poll, if the NFC reader sees the same
# spool that HH already knows about, the dispatch is suppressed (no redundant
# MMU_GATE_MAP call).  Call this after a Klipper restart if startup_polling is
# manual, or any time you want to re-align the NFC cache with HH state.
#
gcode:
    {% set num      = printer.mmu.num_gates | int %}
    {% set spool_ids = printer.mmu.gate_spool_id %}
    {% set statuses  = printer.mmu.gate_status %}
    RESPOND PREFIX="NFC" MSG="Syncing NFC cache from Happy Hare gate map ({num} gates)..."
    {% for i in range(num) %}
        {% set spool_id = spool_ids[i] | default(-1) | int %}
        {% set status   = statuses[i]  | default(0)  | int %}
        RESPOND PREFIX="NFC" MSG="  Gate {i} → lane{i}  spool_id={spool_id}  status={status}"
        NFC GATE={i} HH_SYNC=1 SPOOL_ID={spool_id}
    {% endfor %}
    RESPOND PREFIX="NFC" MSG="Sync complete. Run NFC GATE=N READ=1 to start polling."
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

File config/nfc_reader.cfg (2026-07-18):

# EMU NFC GATE READER USER SETTINGS -------------------------------------------
# Supported documented path:
#   NFC reader over I2C on each lane MCU / EBB42 board.
#   PN532 is the default reader; PN7160 is also supported for rich reads.
#   RC522 and PN5180 are supported as SPI readers. PN5180 also supports
#   SLIX2/ISO15693 Type-5 rich reads and requires reset_pin and busy_pin.
#
# Include order in printer.cfg:
#   [include nfc/nfc_reader.cfg]
#   [include nfc/nfc_macros.cfg]
#   [include nfc/nfc_reader_hw.cfg]
#
# This file defines the base [nfc_gate] section.  Each [nfc_gate laneN]
# section in nfc_reader_hw.cfg inherits these values unless it overrides them.
[nfc_gate]

# NFC reader chip type. Supported: pn532, pn7160, rc522, pn5180.
# PN532 is the default documented path.
# RC522 uses SPI (`cs_pin`, `spi_bus`/software SPI pins, optional `spi_speed`)
# instead of the I2C settings below. It supports UID lookup, NTAG/Type-2 rich
# reads, and authenticated MIFARE/Bambu reads, but not ISO15693.
# PN5180 uses SPI (`cs_pin`, `spi_bus`/software SPI pins, `spi_speed`) plus an
# MCU-controlled `reset_pin` and active-high `busy_pin` (default: mmu:PB0).
# It supports NTAG/Type-2 and SLIX2/ISO15693 Type-5.
# SPI readers default to 500000 Hz with hardware SPI. For software SPI, set
# spi_speed: 100000 explicitly because bit-banged SPI is less tolerant of high rates.
#spi_speed:           500000
reader_type:         pn532

# PN532 default I2C address: decimal 36 == hex 0x24.
# PN7160 valid I2C addresses are decimal 40-43 == hex 0x28-0x2B.
i2c_address:         36
i2c_bus:                 i2c2_PB10_PB11          # SLB configuration
#i2c_bus:                 i2c3_PB3_PB4           # EBB42 configuration 

# SPOOLMAN --------------------------------------------------------------------
# ███████╗ ██████╗   ██████╗   ██████╗  ██╗      ███╗   ███╗  █████╗  ███╗   ██╗
# ██╔════╝ ██╔══██╗ ██╔═══██╗ ██╔═══██╗ ██║      ████╗ ████║ ██╔══██╗ ████╗  ██║
# ███████╗ ██████╔╝ ██║   ██║ ██║   ██║ ██║      ██╔████╔██║ ███████║ ██╔██╗ ██║
# ╚════██║ ██╔═══╝  ██║   ██║ ██║   ██║ ██║      ██║╚██╔╝██║ ██╔══██║ ██║╚██╗██║
# ███████║ ██║      ╚██████╔╝ ╚██████╔╝ ███████╗ ██║ ╚═╝ ██║ ██║  ██║ ██║ ╚████║
# ╚══════╝ ╚═╝       ╚═════╝   ╚═════╝  ╚══════╝ ╚═╝     ╚═╝ ╚═╝  ╚═╝ ╚═╝  ╚═══╝
# Use "auto" to read Moonraker's Spoolman configuration, set a direct URL,
# or set "disabled" to skip Spoolman lookup and use tag metadata directly
# when tag_parsing is enabled.
#
#   spoolman_url: auto
#   spoolman_url: http://192.168.1.50:7912
#   spoolman_url: disabled
spoolman_url:        auto

# Spoolman spool extra field that stores the NFC tag UID.
spoolman_rfid_key:   rfid_tag

# HTTP request timeout in seconds.
spoolman_timeout:    5.0

# Seconds to cache a successful UID -> spool lookup.  0 disables cache.
spoolman_cache_ttl:  300

# TAG DATA RESOLUTION ---------------------------------------------------------
# ████████╗  █████╗   ██████╗     ██████╗   █████╗  ████████╗  █████╗ 
# ╚══██╔══╝ ██╔══██╗ ██╔════╝     ██╔══██╗ ██╔══██╗ ╚══██╔══╝ ██╔══██╗
#    ██║    ███████║ ██║  ███╗    ██║  ██║ ███████║    ██║    ███████║
#    ██║    ██╔══██║ ██║   ██║    ██║  ██║ ██╔══██║    ██║    ██╔══██║
#    ██║    ██║  ██║ ╚██████╔╝    ██████╔╝ ██║  ██║    ██║    ██║  ██║
#    ╚═╝    ╚═╝  ╚═╝  ╚═════╝     ╚═════╝  ╚═╝  ╚═╝    ╚═╝    ╚═╝  ╚═╝
# Choose how tags are resolved:
#
#   tag_parsing: False  -> resolve by UID through Spoolman only
#   tag_parsing: True   -> enable rich RFID content reads when supported
#
# Rich read supports NTAG/Type-2 metadata and authenticated Bambu/MIFARE reads
# on readers with the matching hardware support. RC522 supports both paths over
# SPI; PN7160 additionally supports ISO15693/Type-5.
# Bambu rich reads require pycryptodome in the Klipper Python environment.
tag_parsing:         False

# Allow authenticated Bambu factory-spool reads when tag_parsing is True.
# Leave False unless pycryptodome is installed in the Klipper Python environment.
bambu_reads:         False

# When rich RFID reads produce filament metadata that does not already map to a
# Spoolman spool, allow the plugin to auto-create a new spool record.
spoolman_auto_create: False

# Fallback NTAG user-page window for non-NDEF/binary tags.
# NDEF text/JSON tags are read dynamically from the NDEF TLV length header.
# Default 16 covers the common fixed-size binary formats without extra I2C.
#tag_max_pages: 16
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

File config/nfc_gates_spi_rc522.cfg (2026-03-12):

# =============================================================================
# EMU NFC Gate Reader — Hardware Configuration (SPI / RC522)
# =============================================================================
# Include BOTH files from printer.cfg:
#   [include nfc_macros.cfg]
#   [include nfc_gates_spi_rc522.cfg]
#
# Integration model — UID lookup (Approach B)
# ────────────────────────────────────────────
# Tags are NEVER written to.  Stick any blank 13.56 MHz NFC tag on each spool.
# For each spool, read its tag UID with your phone and paste it into the "rfid"
# extra field on the matching Spoolman spool record.
# See docs/shared/spoolman-integration.md for step-by-step instructions.
#
# Required install steps (do these once):
#   1. Clone the repo and run install.sh — see Readme.md for the one-liner.
#   2. Flash standard Klipper MCU firmware to the Pico with CAN bus support
#      (see docs/spi-rc522/setup.md for make menuconfig settings)
#   3. Find the Pico's CAN UUID and fill in canbus_uuid below:
#        ~/klippy-env/bin/python ~/klipper/scripts/canbus_query.py can0
#   4. Set up the Spoolman "rfid" extra field — see docs/shared/spoolman-integration.md.
#   5. Fill in your Spoolman URL below.
#   6. Restart Klipper:  sudo systemctl restart klipper
#
# Interface: SPI — one RC522 module per gate, CS pins on RP2040 GPIOs
# Driver:    rc522_driver.RC522Driver (ISO14443A / REQA → ANTICOLL only)
# Macros:    nfc_macros.cfg (shared with I2C path — include separately)
# =============================================================================


# -----------------------------------------------------------------------------
# [mcu nfc_pico] — Raspberry Pi Pico as a CAN bus MCU
# -----------------------------------------------------------------------------
# Firmware build settings (make menuconfig):
#   Micro-controller:        Raspberry Pi RP2040
#   Communication interface: CAN bus
#   CAN TX GPIO:             4   (SN65HVD230 CAN transceiver)
#   CAN RX GPIO:             5   (SN65HVD230 CAN transceiver)
#   CAN bus speed:           1000000
#
# Flash via USB (hold BOOTSEL while connecting):
#   make flash FLASH_DEVICE=/dev/sda1
# -----------------------------------------------------------------------------
[mcu nfc_pico]
canbus_uuid: YOUR_UUID_HERE


# -----------------------------------------------------------------------------
# [nfc_gates] — RC522 readers over SPI1
# -----------------------------------------------------------------------------
# Hardware SPI1 on the RP2040 uses fixed silicon pin functions:
#   SCK  = GP10    MOSI = GP11    MISO = GP8
# Each RC522 gets its own CS (chip-select) GPIO.
#
# Gate 0: cs_pin = gpio0
# Gate 1: cs_pin = gpio1   (add to extra_cs_pins)
# Gate 2: cs_pin = gpio2   ...
# Gate 3: cs_pin = gpio3
# Gate 4: cs_pin = gpio6   (gpio4/5 reserved for CAN TX/RX)
# -----------------------------------------------------------------------------
[nfc_gates]

# Gate 0 CS — also selects the SPI bus for all gates
cs_pin:  nfc_pico:gpio0
spi_bus: spi1
spi_speed: 1000000          # 1 MHz — reliable over jumper wires

# Additional gate CS pins (gates 1–N), comma-separated.
# Remove entries to match your physical wiring (minimum: 1 gate total).
extra_cs_pins: nfc_pico:gpio1, nfc_pico:gpio2, nfc_pico:gpio3, nfc_pico:gpio6

# ── Spoolman integration ──────────────────────────────────────────────────────
# REQUIRED: URL of your Spoolman instance.
# Common values:
#   http://mainsailos.local:7912       (MainsailOS default hostname)
#   http://192.168.1.50:7912           (static IP)
spoolman_url: http://mainsailos.local:7912

# Name of the extra field in Spoolman that holds the tag UID (default: rfid).
# Must match the field name you created in Settings → Extra fields → Spool.
# spoolman_rfid_key: rfid

# HTTP request timeout in seconds (default 5.0).
# spoolman_timeout: 5.0

# Seconds to cache a successful UID→spool_id mapping (default 300 = 5 min).
# Cached entries avoid a Spoolman API call when the same tag is still present.
# spoolman_cache_ttl: 300

# ── Polling ───────────────────────────────────────────────────────────────────
# How often to poll all gates (seconds).
poll_interval: 30

# Consecutive missed polls before a spool is declared removed.
# At 30 s/poll: 3 misses ≈ 90 s of absence before REMOVED fires.
absent_threshold: 3

# Seconds to wait after triggering TRANSCEIVE before reading the result.
# RC522 internal timer fires at ~0.5 ms when no tag present; tags respond in
# <2 ms.  35 ms is conservative and accounts for CAN bus round-trip latency.
transceive_delay: 0.035

# ── Logging ───────────────────────────────────────────────────────────────────
# Logging verbosity written to klippy.log.
#   0 — errors and warnings only
#   1 — major events: poll cycles, tag detected/removed, Spoolman lookups (default)
#   2 — full trace: every SPI register read/write, FIFO contents, IRQ flags
debug: 1

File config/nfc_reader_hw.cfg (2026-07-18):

# =============================================================================
# ================= EMU NFC GATE READER - NFC I2C LANE HARDWARE ================
# =============================================================================
# Supported documented path:
#   one NFC reader module per lane MCU / EBB42 board.
#   PN532 is the default reader; PN7160, RC522, and PN5180 may be selected per
#   lane with reader_type. SPI readers need spi_bus and cs_pin; PN5180 also
#   requires BUSY and RST. See docs/i2c-nfc/pn5180-wiring.md for the SLB setup.
#
# Include after nfc_reader.cfg and nfc_macros.cfg:
#   [include nfc/nfc_reader.cfg]
#   [include nfc/nfc_macros.cfg]
#   [include nfc/nfc_reader_hw.cfg]
#
# The base [nfc_gate] section in nfc_reader.cfg defines defaults for all
# lanes. Each [nfc_gate laneN] section below inherits those keys automatically.
# Override a key in a lane section only when that lane needs a different value.
# Example:
#   [nfc_gate]
#   reader_type: pn532
#   i2c_address: 36
#   i2c_bus:     i2c3_PB3_PB4
#   scan_enabled: False
#
#   [nfc_gate lane1]
#   mmu_gate:     1
#   i2c_mcu:      lane1
#   reader_type:  pn532
#   scan_enabled: True
#
# Address note:
#   PN532 has a fixed I2C address, so lanes normally inherit i2c_address: 36
#   from the base [nfc_gate] section.
#
#   PN7160 can use multiple I2C addresses selected by hardware address pins or
#   DIP switches. In the common EMU layout, each lane has its own MCU/I2C bus,
#   so all PN7160 lanes may use the same inherited address. If multiple PN7160
#   readers share one MCU/I2C bus, give each reader a unique i2c_address in its
#   [nfc_gate laneN] section, for example:
#
#     reader_type:  pn7160
#     i2c_address:  40     # 0x28; other PN7160 addresses may be 41-43
#
# RC522 note:
#   RC522 can be used per lane if that lane section provides Klipper SPI
#   settings (`cs_pin`, `spi_bus`/software SPI pins) instead of
#   i2c_address/i2c_bus.
#   See nfc_reader_shared.cfg for a copyable RC522 shared-reader example.
#
#   Example RC522 lane override:
#
#     [nfc_gate lane1]
#     enabled:      True
#     mmu_gate:     1
#     i2c_mcu:      mmu1
#     reader_type:  rc522
#     cs_pin:       mmu1:PA4
#     spi_bus:      spi1
#     spi_speed:    500000  # hardware SPI default; use 100000 for software SPI
#     #rc522_transceive_delay: 0.035
#
# Each [nfc_gate laneN] section maps:
#   Happy Hare gate number -> Klipper lane MCU -> NFC reader hardware.
# startup_poll_delay staggers automatic startup polling so all readers do not
# enter their first poll cycle at the same time.
# Each [mmu_nfc_endstop laneN] section seeds Happy Hare with a homeable virtual
# endstop that uses the matching lane reader. Use ENDSTOP=nfc_laneN in Happy
# Hare homing/test moves.
#
# Happy Hare V4 / multi-unit example:
#   Section names are labels only. The nfc_gate reference binds the virtual
#   endstop to its reader, while mmu_gate is Happy Hare's global gate number.
#   For example, the first physical lane of unit0 can be configured as:
#
#     [nfc_gate unit0_lane0]
#     enabled:                True
#     mmu_gate:                0
#     i2c_mcu:                 unit0_gate0
#     startup_poll_delay:      0.0
#
#     [mmu_nfc_endstop unit0_lane0]
#     nfc_gate:                unit0_lane0
#     endstop_name:            nfc_unit0_lane0
#     poll_interval:           0.05
#     register_sensor:         True
#
#   A second unit's first lane might use mmu_gate: 4. Happy Hare V4 resolves
#   that global gate to the correct unit drive automatically.
# Set enabled: False on a lane to keep the template in place without creating
# the I2C reader, registering the GCode mux command, or initializing hardware.
#
# i2c_mcu: is consumed by Klipper's I2C bus layer (MCU_I2C_from_config),
# not read explicitly by the plugin.  The MCU name must already exist in
# Klipper / Happy Hare config.  Example: [mcu lane0], [mcu lane1], etc.
#
# [WARN] After updating Klipper, rebuild and flash the lane MCU / EBB42 firmware.
# Updating the host alone is not enough for NFC reader I2C troubleshooting.
# =============================================================================

# =============================================================================
# ================================= LANE 0 =====================================
# =============================================================================
[nfc_gate lane0]
enabled:                True
mmu_gate:                0
i2c_mcu:                 mmu0
startup_poll_delay:      0.0

[mmu_nfc_endstop lane0]
nfc_gate:                lane0
endstop_name:            nfc_lane0
poll_interval:           0.05
register_sensor:         True
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

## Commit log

2026-03-12 Initial Comit
    [nfc_gate_i2c_pn532.cfg, nfc_gates_spi_rc522.cfg, nfc_macros.cfg]
2026-04-10 klipper path fixed for the bus import
    [nfc_gate_i2c_pn532.cfg]
2026-04-10 variable management
    [nfc_gate_i2c_pn532.cfg, nfc_vars.cfg]
2026-04-11 rework PN532 wake-up: two-phase read + longer cold-start delay
    Previous approach sent GetFirmwareVersion then called _recv() which
    reads the status byte as part of a single i2c_read — but Klipper's
    MCU_I2C raises if the chip NACKs the read, not just the write.
    New approach:
    1. Send command frame (same as before)
    2. Read exactly 1 byte to check the PN532 status flag (0x01=ready)
    — if busy/not-ready, wait 30ms and retry without sending again
    3. Only once status=0x01, read the remaining 14 bytes for the frame
    Also increases attempts 1→10, uses 100ms post-TX wait on the first
    attempt (cold-start settling) and 50ms on subsequent attempts.
    debug=2 logs the status byte value and READY/BU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
    [pn532_driver.py]
2026-04-14 synching with HH, modified polling and startup
    [nfc_macros.cfg]
2026-04-19 fixing corner cases where polling should stop. Don't want false empty lanes
    [nfc_macros.cfg]
2026-04-19 fixed status message, removed klipper object name
2026-04-22 New PN532 NFC hanger with guard
    [LED_holder_NFC_Guard.stl, LED_holder_No_cover_with_NFC.stl, LED_holder_with_NFC.step]
2026-04-23 updated LED_NFC hanger
    [LED_holder_NFC_Guard.step, LED_holder_No_cover_with_NFC.step, LED_holder_with_NFC.step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]
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2026-04-29 configuration for ebb and SLB. inherit bus from nfc_vars.cfg
    [nfc_vars.cfg, pn532_i2C.cfg]
2026-04-29 aligning to HH/addon file and operating structures. all files changed to ready for mass testing
    [nfc_vars.cfg, pn532_i2C.cfg]
2026-04-29 moving to conform to HH/addon structure and archtypes
    [nfc_macros.cfg, nfc_reader.cfg, nfc_reader_hw.cfg]
2026-05-03 stabalizing brittle state engine bug fixing
    [nfc_reader.cfg]
2026-05-04 added the mmu_spoolman synch=1 and removed all location methods
    [nfc_macros.cfg]
2026-05-04 implemented trace callbacks and logging to hook into lameandboards functions but still use the nfc logger
2026-05-09 Allow scan-jog to skip HH Spoolman sync
    [nfc_manager.py, scan_jog.py]
2026-05-11 Use finer default decode retry spacing
    Change scan-jog decode retry defaults to 2.0mm and 5 rounds so Bambu/MIFARE retries probe a finer +/-2mm grid around the first UID hit.
    The updated default covers offsets from +/-2mm through +/-10mm, which matched printer logs where full Bambu block reads succeeded at an offset missed by the previous 5mm grid.
    Update shipped config, docs, and config tests to reflect the new defaults.
    [nfc_reader.cfg]
2026-05-11 Log parsed filament temperature metadata
    Include min/max hotend, bed, and drying temperature fields in the tag metadata summary log.
    Bambu tags already parse these values and downstream code may use them for Happy Hare or Spoolman metadata, but the compact parsed-tag log omitted them. Showing the fields makes it possible to verify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
2026-05-11 removed all the emoji's replaced with
    Emoji Replaced with Location
    📡 [CONNECTED] nfc_manager.py
    ❌ [WARN] nfc_manager.py
    ✅ [OK] nfc_manager.py
    ⚠️ [WARN] nfc_manager.py
    🔍 [SCAN] nfc_manager.py, scan_jog.py, 3× test_scan_jog_mode.py
    added the scan retry to the NDEF tags,
    added a mifare base sector decode function, started impmenteing but commmented the
    Creatlity logic for decoding the tags. Don't have tags to test the code, so it would be
    irresonsible to put a branch out there and not having even unit tested it.
    [nfc_manager.py, scan_jog.py, tag_handler.py]
2026-05-14 fixing the logging messaging
    redoing all the log prefexes and messages. cleaning it up, readying for consistent archtypes
    [scan_jog.py]
2026-05-18 Sync from private repo
    [nfc_macros.cfg, nfc_reader_shared.cfg]
2026-06-16 Introduce NFC reader factory
    Move reader type validation, I2C construction, and PN532Driver creation behind a reader_factory module so nfc_manager no longer instantiates PN532Driver directly.
    Keep pn532 as the only integrated driver for now and preserve the explicit error for recognized reader types whose drivers are not wired in yet.
    [nfc_manager.py, reader_factory.py]
2026-06-16 Validate PN7160 I2C address range
    Reject PN7160 reader configs whose final i2c_address is outside 40-43 (0x28-0x2B) before creating the MCU I2C object.
    This catches accidental PN532/default addresses early and makes PN7160 bring-up failures easier to diagnose.
    [reader_factory.py]
2026-06-18 Try reversed UID for PN7160 MIFARE auth
    Keep Bambu key derivation on the activation UID, but reverse the UID bytes only in the PN7160 MIFARE Classic auth helper payload.
    This isolates UID byte order as the next protocol variable after key/UID field order still produced only CORE_CONN_CREDITS and no DATA frame for the following MIFARE READ.
2026-06-18 Document PN7160 shared reader configuration
    Update the shared reader template and shared-reader guide to describe shared hardware generically as an NFC reader instead of PN532-only hardware.
    Keep the shipped default as PN532 by leaving reader_type and i2c_address commented in nfc_reader_shared.cfg, while showing the PN7160 override and its valid I2C address range. Also update NFC_SHARED 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
    [nfc_reader_shared.cfg]
2026-06-18 Document PN7160 START_NACK troubleshooting
    Add quick links to the NFC troubleshooting guide so users can jump directly to common startup, reader, and tag-resolution failures.
    Document the PN7160 connect_nci CORE_RESET START_NACK error as an I2C communication failure. The guidance points users at wiring, bus/address, power, shared ground, and reset-state checks, then recommends power-cycling the PN7160 when VEN is not wired and the chip still does not respond.
2026-06-20 setting the timing between continuous scans to 0.1 second
    [nfc_reader.cfg]
2026-06-20 setting continuous as the default scan_jog model
    [nfc_reader.cfg]
2026-06-24 updating installer to add spoolman_url: disable, and the additional fields from the rich tag read. easiest migration for this version is to run install again, or - copy nfc_macros.cfg to your config 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
    [nfc_macros.cfg]
2026-06-26 Probe immediately after continuous scan moves
    The previous continuous scan scheduling queued a move and then waited scan_continuous_poll_interval before the first UID probe. After removing the stopped end-of-chunk full poll, that exposed a timing hole: Direct Move often returns with only 50-60ms of estimated movement left, so a 100ms first-probe delay lets the state machine consider the chunk complete before any UID probe runs.
    Add a per-chunk _scan_continuous_probe_due flag. Each queued continuous move now schedules the scan timer immediately and guarantees at least one short UID probe for that move, even if the estimated move-complete time has already passed by the time the reactor callba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
    [scan_jog.py]
2026-06-26 Use queued move time for continuous Direct Move scans
    Continuous scan Direct Move was still using expected_duration minus command_elapsed to decide when the current chunk had finished. Logs showed command_elapsed mostly represented Klipper/Happy Hare queueing work, while mmu_toolhead.get_last_move_time() minus MCU estimated_print_time() still had about 0.35-0.41s of queued motion remaining.
    Record the Direct Move queue_remaining value immediately after the move is queued and use it as the move completion delay. This keeps UID probes active during the actual queued motion and prevents rich tag handling from starting while the spool is still moving.
    Non-direct fallback moves keep the previou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
    [scan_jog.py]
2026-06-27 Remove temporary Type-B stepper state logging
    Drop the diagnostic logging that printed selected gear stepper and stepper_enable state before each continuous Direct Move.
    The logs confirmed that only the first NFC scan chunk started with the lane stepper disabled and later chunks remained enabled, so the temporary instrumentation is no longer needed.
    [scan_jog.py]
2026-06-30 Tune continuous scan hit-window positioning
    Raise the default continuous scan step to 150mm now that rich reads recenter on the observed UID hit window instead of relying on small forward chunks.
    Remove the scan_continuous_overshoot_backup_mm configuration path. A stationary startup poll that sees an incomplete rich tag should use the normal scan_decode_retry_mm sweep, while in-motion UID hit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
    Update README, config comments, shared documentation, and changelog text to describe hit-window recentering and the new continuous defaults.
    [nfc_reader.cfg]
2026-07-07 cleaned up the V4 assessment and cleaned up the specific states allowed by manual call and branch for the automated call from teh happy hare hook. There are now only 2 status allowed -- idle or check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
    [nfc_macros.cfg, nfc_reader.cfg]
2026-07-08 fixing the happy hare travel distance display to mimic mmu_load beahvior
    [scan_jog.py]
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2026-07-12 seeding the spool_identity for spoolman resolved UID if there is a rich tag being read
    [scan_jog.py, tag_handler.py]
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2026-07-17 releasing the Happy Hare LED effect and reseting the gate_map to make sure happy hare is in control of the LED's post parking the filament
    [scan_jog.py]
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2026-07-18 Set conservative SPI defaults for NFC readers
    Use 500kHz as the default SPI clock for both RC522 and PN5180 when hardware SPI is configured.
    Document 100kHz as the recommended explicit setting for software SPI, where bit-banged timing is less tolerant of high rates.
    Align installer prompts, shared and lane configuration examples, and configuration reference text; use the SLB spi2_PB14_PB15_PB13 bus in the shared RC522 example.
    [nfc_reader.cfg, nfc_reader_hw.cfg, nfc_reader_shared.cfg]
2026-07-18 Document PN5180 wiring and SLIX2 support
    Add a dedicated PN5180 wiring guide with the verified nine-wire SLB connection: 5V, PSF 3.3V, ground, SPI2, NSS, BUSY, and RST.
    Document BUSY and RST as mandatory, explain hardware and software SPI speed guidance, and add PN5180 configuration, installation, and troubleshooting coverage.
    Update reader capability matrices to include PN5180 MIFARE/Bambu support and clarify that the current Type-5 rich-read path targets SLIX2 tags whose payload is passed to the common parser, not only O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
    [nfc_reader.cfg, nfc_reader_hw.cfg, nfc_reader_shared.cfg]
2026-07-19 Route shared preload hook to lane readers
    Use the single Happy Hare post-preload hook as a router: enabled per-lane readers always run their existing scan-jog path, while gates without a lane reader retain the shared-reader spool staging pat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
    Determine reader ownership from configured mmu_gate values rather than section names, supporting Happy Hare V3, V4, multi-unit, and custom layouts.
    [nfc_macros.cfg]
